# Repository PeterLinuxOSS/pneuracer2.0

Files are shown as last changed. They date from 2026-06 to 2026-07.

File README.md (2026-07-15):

# 🏎️ Pneuracer 2.0

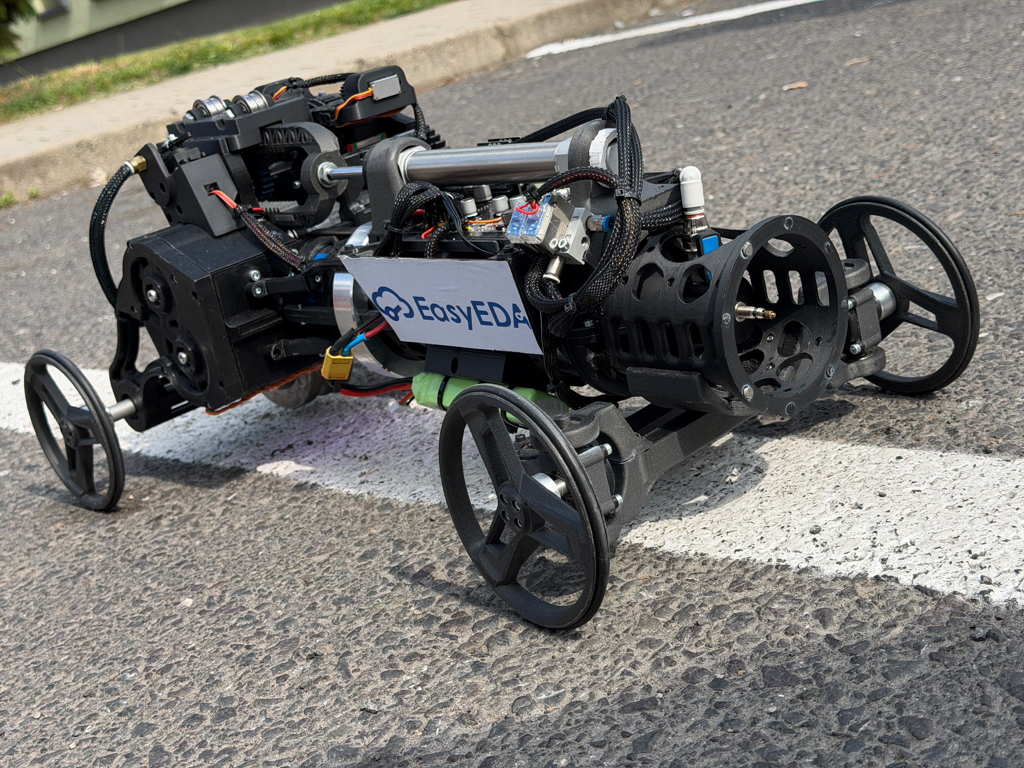
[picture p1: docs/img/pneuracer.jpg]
Pneuracer 2.0


> Control-system firmware for a **compressed-air powered** race car — no fuel, no electric motors.
> Student project by team **FLUJD** · SPŠ techniky a dizajnu, Poprad 🇸🇰

Two **ESP32-S3** chips (master + slave) talk over UART and together run the drivetrain, steering, tilt detection and diagnostics. Built with **PlatformIO** — one repository, two firmware images. Every part, circuit and line of code was designed and built by the team.

---

## 🏆 Highlights

- 🥇 **Regional winners** — ENERSOL SK (best project of the round)
- 🥈 **2nd place** — ENERSOL SK national → international final (Senica, V4 + Austria)
- 🥈 **2nd place** — Strojár Inovátor, TU Košice
- 4️⃣ **4th** — SOČ national
- 4️⃣ **4th / 40** — international Pneuracer, Brno *(+6 vs. last year)*

## 🚀 Quick start

```bash
git clone https://github.com/PeterLinuxOSS/pneuracer2.0.git
cd pneuracer2.0

pio run -e master_esp --target upload   # flash the master
pio run -e slave_esp  --target upload   # flash the slave
pio device monitor                      # 921600 baud
```

## 📚 Documentation

- 📖 **[Technical docs](docs/TECHNICAL.md)** — architecture, comms protocol, control modes, tuning, datasheets
- 📦 **[Bill of materials](docs/BOM.md)** — electronics + pneumatic kit
- 🔩 **[Hardware / PCB](docs/hardware/)** · 📐 **[Schematics](docs/schematics/)**
- 🗺️ **[Roadmap / TODO](TODO.md)** — planned improvements for the next PCB revision
- 📸 **[Gallery](docs/GALLERY.md)** — photos of the car and the team

## 🤝 Sponsors & partners

<p align="center">
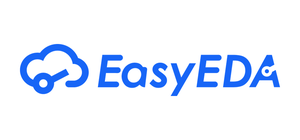
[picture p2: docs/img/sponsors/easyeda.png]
EasyEDA
  
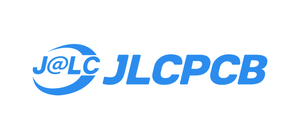
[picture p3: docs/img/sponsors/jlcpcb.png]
JLCPCB
  
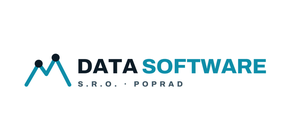
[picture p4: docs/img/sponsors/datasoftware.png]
DataSoftware s.r.o. Poprad
  
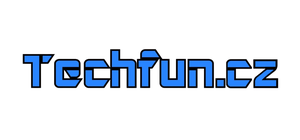
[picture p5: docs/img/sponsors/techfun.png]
Techfun.cz
  
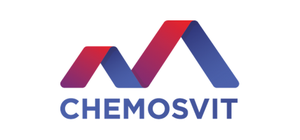
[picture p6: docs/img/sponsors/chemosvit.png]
Chemosvit
  
</p>

**[EasyEDA](https://easyeda.com)** & **[JLCPCB](https://jlcpcb.com)** — PCB design & manufacturing · **[DataSoftware](https://www.datasoftware.sk)** — electronic components · **[Techfun.cz](https://techfun.cz)** — electronics know-how & PCB review · **[Chemosvit](https://www.chemosvit.sk)** — travel & logistics. Huge thanks! 🙏

## 👤 Team

Team **FLUJD** — SPŠ techniky a dizajnu, Poprad 🇸🇰
**Peter Rigo** (lead — electronics, firmware) · Matej Mikita · Tomáš Frankovský · Tobias Cehula

📧 [rigopeter11@gmail.com](mailto:rigopeter11@gmail.com) · 📷 [@flujdsk](https://instagram.com/flujdsk)

## 📄 License

© 2026 Team FLUJD (Peter Rigo, Matej Mikita, Tomáš Frankovský, Tobias Cehula). Open source under copyleft:

- **Firmware & source code** — [GNU GPL v3.0](LICENSE). Derivatives must stay open-source under the same license.
- **Hardware, schematics, PCB files, CAD & documentation** — [CC BY-SA 4.0](LICENSE-HARDWARE.txt). Share alike, with attribution.

You are free to use, study, modify and share the project — just keep it open and credit **Team FLUJD**.

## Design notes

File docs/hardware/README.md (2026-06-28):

# 🔩 Hardware — PCB design files

EasyEDA Pro design files and manufacturing outputs for the Pneuracer 2.0 boards.

## Boards

| Folder | Board | Description |
|---|---|---|
| [`main-board/`](main-board/) | **Main board** (codename *Flujd*) | Carries the ESP32-S3 master/slave control electronics. |
| [`switching-regulator/`](switching-regulator/) | **Switching regulator** | Step-down power module — **2× placed on the main board**. |

## Files (per board)

| File | Description |
|---|---|
| `*.epro2` | EasyEDA Pro project (schematic + PCB) — open in [EasyEDA Pro](https://pro.easyeda.com) |
| `gerber.zip` | Gerber + drill files for manufacturing (e.g. JLCPCB) |
| `bom.xlsx` | Bill of materials for assembly |
| `pick-and-place.xlsx` | Component placement (CPL) for SMT assembly |
| `interactive-bom.html` | Interactive BOM — open in a browser for hand-assembly |

> System-level wiring schematics (draw.io) are in [`../schematics/`](../schematics/).
> Component-level BOM with order numbers is in [`../BOM.md`](../BOM.md).

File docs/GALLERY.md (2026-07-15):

# 📸 Gallery — Pneuracer 2.0

Photos of the car and the team from the 2025/2026 competition season.

<table>
  <tr>
    <td width="50%">Pneuracer 2.0<br><sub>The car — compressed-air powered, 3D-printed chassis</sub></td>
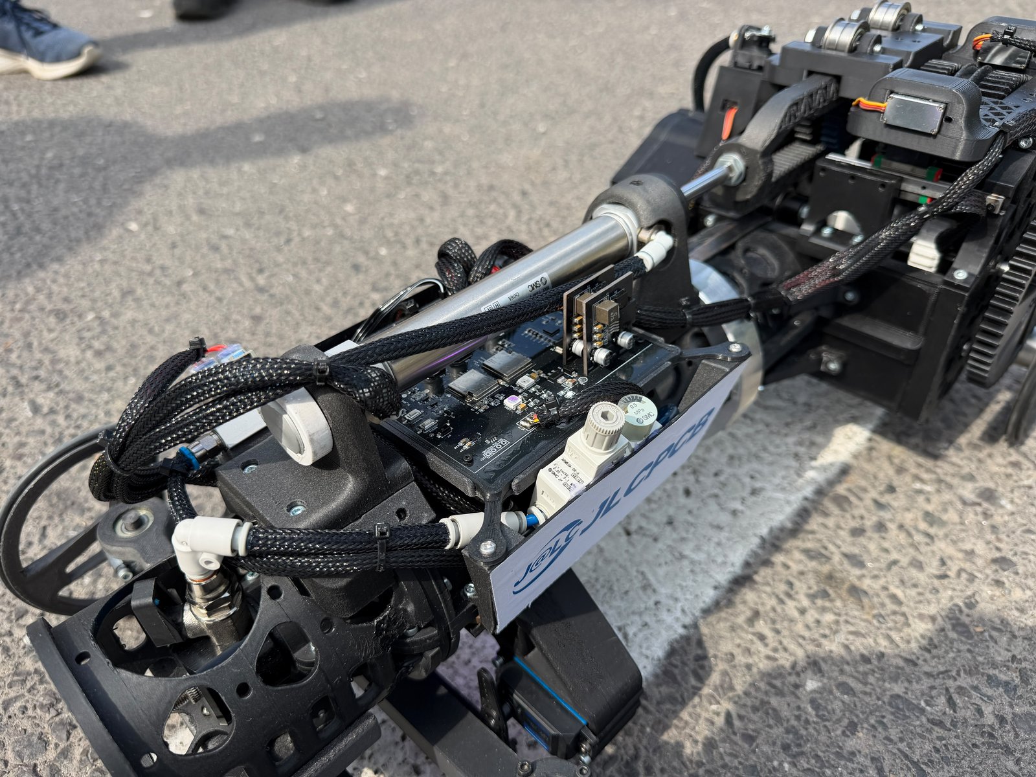
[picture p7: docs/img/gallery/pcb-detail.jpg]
Custom electronics
    <td width="50%"><br><sub>Custom ESP32-S3 control board & pneumatics on-board</sub></td>
  </tr>
  <tr>
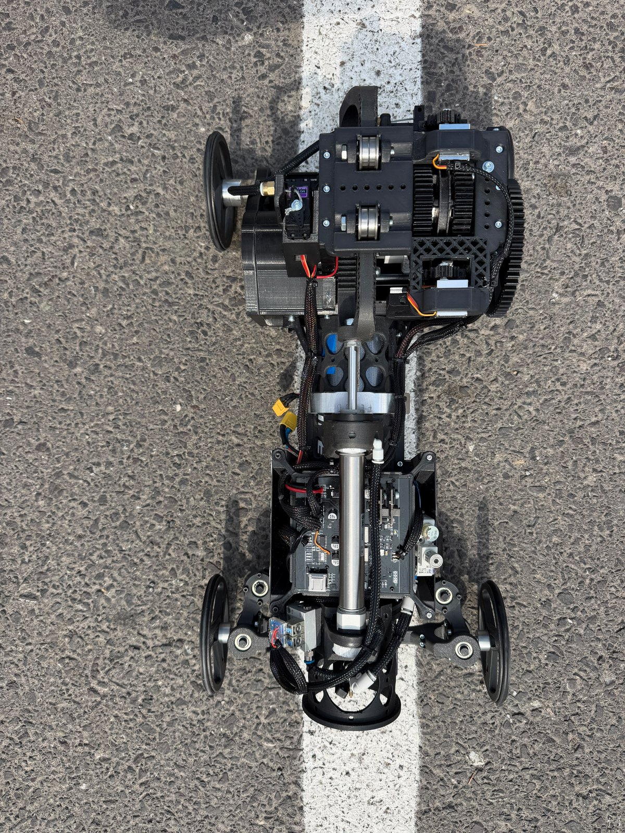
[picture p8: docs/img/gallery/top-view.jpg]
Top view
    <td width="50%"><br><sub>Top-down view — drivetrain & electronics layout</sub></td>
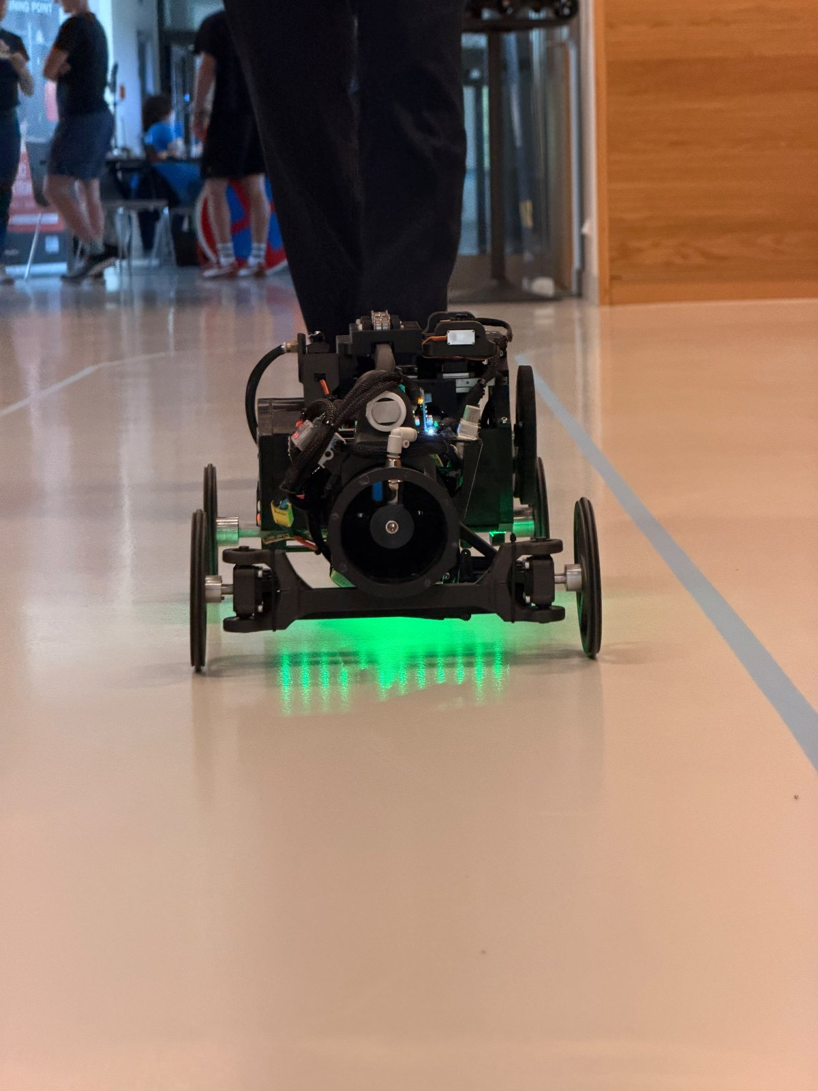
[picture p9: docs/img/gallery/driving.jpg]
Driving
    <td width="50%"><br><sub>Running at the international Pneuracer competition, Brno</sub></td>
  </tr>
  <tr>
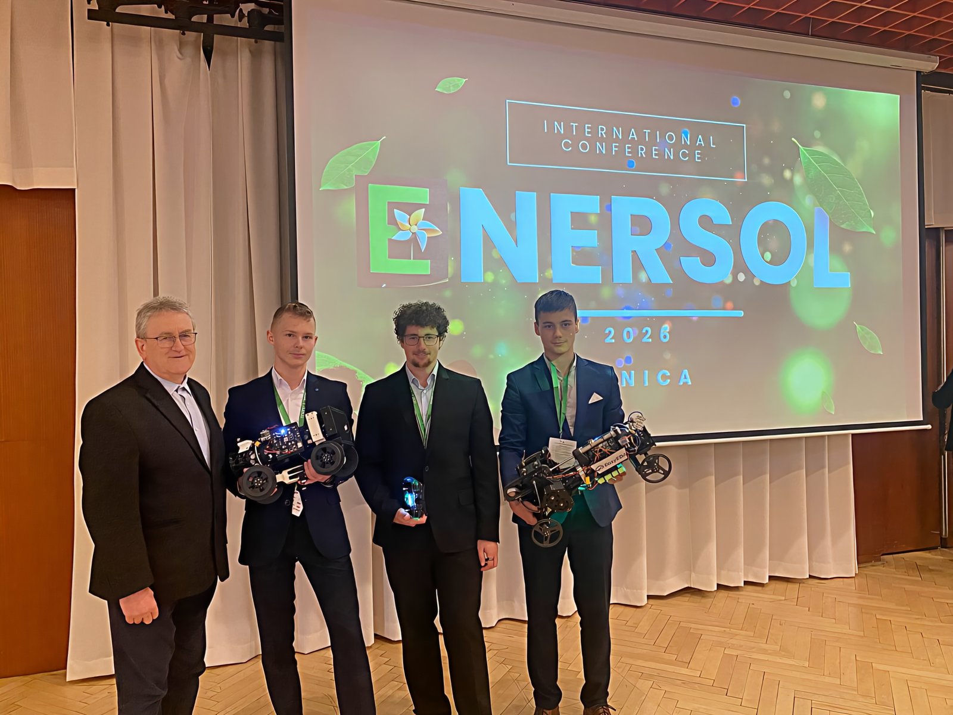
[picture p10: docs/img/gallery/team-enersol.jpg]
Team FLUJD at ENERSOL
    <td width="50%"><br><sub>Team FLUJD with the car at ENERSOL</sub></td>
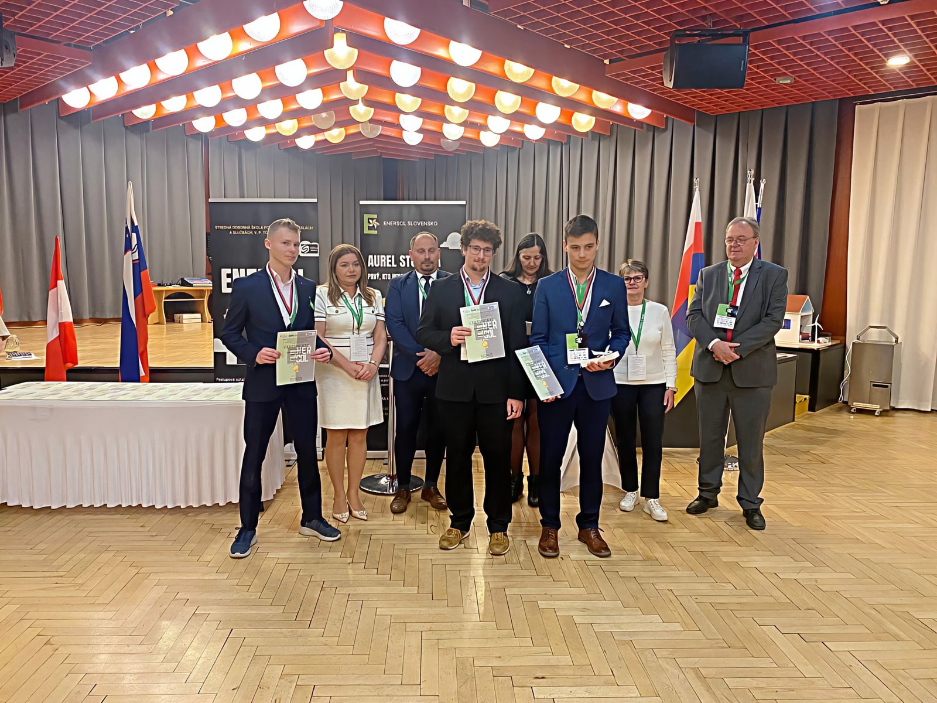
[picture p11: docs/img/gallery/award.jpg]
Award ceremony
    <td width="50%"><br><sub>Award ceremony — international ENERSOL final (V4 + Austria)</sub></td>
  </tr>
</table>

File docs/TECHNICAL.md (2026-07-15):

# 🔧 Pneuracer 2.0 — Technical documentation

Detailed technical reference for the Pneuracer 2.0 firmware. For a short overview see the [main README](../README.md).

---

## 🏗️ System architecture

Two ESP32-S3 chips communicate over UART; the shared `ControlPacket` structure ([`src/shared/SharedData.h`](../src/shared/SharedData.h)) defines the link.

```
[RC transmitter 2.4 GHz]
        │  ELRS/CRSF protocol
        ▼
┌──────────────────────────────┐              UART 921 600 baud               ┌─────────────────────────────────┐
│      ESP32-S3  MASTER        │ ◄───────────────────────────────────────────►│       ESP32-S3  SLAVE           │
│                              │          SharedData.h (ControlPacket)        │                                 │
│ • ELRS/CRSF receiver         │          header 0xBEEF + checksum            │ • Solenoid valves A/B           │
│ • IMU LSM6DS (tilt detect.)  │                                              │ • Pneumatic servo (gearbox)     │
│ • NeoPixel strip (29 LEDs)   │                                              │ • AS5600 magnetic encoder       │
│ • Servos: steering, brake    │                                              │ • Hall sensors (start/end)      │
│ • Buzzer                     │                                              │ • NeoPixel LED (1 pc)           │
│ • ADC: battery, current      │                                              │ • FreeRTOS TaskComms + Mutex    │
└──────────────────────────────┘                                              └─────────────────────────────────┘
```

---

## ⚙️ Hardware components

| Component | Side | Description |
|---|---|---|
| ESP32-S3 (×2) | Master + Slave | `esp32-s3-devkitc-1` |
| LSM6DS | Master | IMU — tilt detection |
| LSM6DSOX | Slave | IMU — supplementary measurement |
| AS5600 | Slave | Magnetic encoder (I²C) — angular speed °/s |
| Hall sensors | Slave | `HALL_START` pin 7, `HALL_END` pin 8, threshold 2000 |
| Solenoid valves | Slave | `VALVE_A` pin 6, `VALVE_B` pin 5 |
| Pneumatic servo | Slave | `SERVO_AIR_REG` pin 4 — gear shifting |
| ELRS receiver | Master | CRSF, Serial2: RX=4, TX=5 |
| NeoPixel strip | Master | 29 LEDs, pin 3 — Knight Rider boot animation |
| NeoPixel | Slave | 1 LED, pin 34 — status indication |
| Steering servo | Master | Pin 16 |
| Brake servo | Master | Pin 35 |
| Buzzer | Master | Pin 38, 1500 Hz |
| Battery ADC | Master | Pin 15, 3S LiPo (9–12.6 V) |
| Current ADC | Master | Pin 12 |

Full parts list (control electronics + SMC pneumatic kit): [`BOM.md`](BOM.md).

---

## 🔌 Master ↔ Slave communication protocol

The UART link runs at 921 600 baud. Every packet has a `0xBEEF` header and a checksum:

```cpp
// src/shared/SharedData.h
const uint16_t PACKET_HEADER = 0xBEEF;

struct __attribute__((packed)) ControlPacket {
    uint16_t header;         // 0xBEEF — packet identifier
    bool     motorEnable;    // motor enable
    int16_t  throttle;       // throttle from RC
    bool     elrsActive;     // ELRS link status
    int16_t  button;         // button state
    bool     haltIMU;        // pause IMU protection
    bool     brake;          // brake
    bool     Automatic;      // automatic mode
    int16_t  AutomaticSpeed; // controller setpoint (°/s)
    int16_t  Gear;           // requested gear
    uint8_t  checksum;       // checksum (summed XOR)
};
```

The slave processes packets in the FreeRTOS task `TaskComms` guarded by the `dataMutex` semaphore — the main loop never reads the data directly without locking.

---

## 🤖 Control modes (Slave)

**Manual mode** — the `throttle` value is mapped to the pause duration between valve switching. More throttle = shorter pause = higher output.

**Automatic mode — P controller** — the slave measures angular speed with the AS5600 encoder and compares it against the `AutomaticSpeed` setpoint, correcting the valve delay:

```cpp
float error      = automaticTargetSpeed - angular_speed;  // °/s
float adjustment = AUTO_KP * error;                       // KP = 0.04
currentDelayTarget -= (long)constrain(adjustment,
                                      -AUTO_MAX_ADJUSTMENT,
                                       AUTO_MAX_ADJUSTMENT);
```

**Automatic gear shifting:**

| Condition | Action | Servo (µs) |
|---|---|---|
| speed ≥ 1600 °/s | 3rd gear | 1200 |
| speed < 1400 °/s | 1st gear | 1800 |
| otherwise | Neutral | 1450 |

The hysteresis guard `GEAR_SHIFT_DELAY_MS = 250 ms` prevents rapid gear hunting.

---

## 🛠️ Building and flashing

**Requirements:** Visual Studio Code + PlatformIO extension, or the PlatformIO CLI (`pip install platformio`).

```bash
git clone https://github.com/PeterLinuxOSS/pneuracer2.0.git
cd pneuracer2.0

pio run -e master_esp --target upload   # flash the MASTER ESP32-S3
pio run -e slave_esp  --target upload   # flash the SLAVE ESP32-S3
pio device monitor                      # 921600 baud
```

> **Ports:** Master looks for `hwgrep://Standard COM Port`, Slave `hwgrep://Enhanced COM Port`.
> Change `upload_port` in `platformio.ini` to match your system if needed.

**Libraries** (PlatformIO downloads them automatically):

| Library | Version | Where |
|---|---|---|
| `Adafruit NeoPixel` | ^1.15.2 | Master + Slave |
| `CRSFforArduino` | ^2025.12.11 | Master |
| `Adafruit LSM6DS` | ^4.7.4 | Master + Slave |
| `ESP32Servo` | ^3.1.3 | Master + Slave |
| `AS5600` (robtillaart) | ^0.6.7 | Master + Slave |
| `Arduino_LSM6DSOX` | ^1.1.2 | Slave |

---

## 🎛️ Parameter tuning

All tunable values live in `config.h` — no "magic numbers" in the code.

`src/slave/config.h` — controller and valves:

```cpp
#define AUTO_KP               0.04f   // proportional gain
#define AUTO_MAX_ADJUSTMENT   15      // max delay change per cycle (ms)
#define AUTO_DEFAULT_SPEED    2000.0f // target speed when no setpoint arrives (°/s)
#define GEAR_UP_SPEED         1600.0f // shift up (°/s)
#define GEAR_DOWN_SPEED       1400.0f // shift down (°/s)
#define CONNECTION_TIMEOUT_MS 500     // failsafe on communication loss (ms)
```

`src/master/config.h` — battery and safety:

```cpp
#define TILT_WARNING_THRESHOLD   30.0f  // warning angle (°)
#define TILT_CRITICAL_THRESHOLD  45.0f  // critical angle (°)
#define BATTERY_VOLTAGE_MIN      9.0f   // min 3S LiPo voltage (V)
#define BATTERY_VOLTAGE_CRITICAL 9.0f   // triggers error state (V)
```

---

## 🧩 3D model (`Model/`)

The [`Model/`](../Model/) folder contains the 3D CAD model exported from **Onshape**:

- `Assembly 1.step` — full vehicle assembly in the neutral **STEP** format (ISO 10303); opens in any CAD package (Fusion 360, SolidWorks, FreeCAD, Onshape, …).
- Live Onshape document: <https://cad.onshape.com/documents/b738f9fed58a0fc4300e86a8/w/2e6fb48d5bbfbd61ad92da93/e/82aa846a4fa390a4291205c2>

---

## 🎮 Transmitter — EdgeTX SD card (`edgetx_sdcard/`)

Ready-to-use **EdgeTX** SD card content for the RadioMaster transmitter that controls the car over ELRS/CRSF.

- Firmware target: **`pocket`** · EdgeTX **v2.11.4**
- `MODELS/` — transmitter model configs (`model00.yml` … `model04.yml`), including the Pneuracer model
- `RADIO/` — global radio settings (`radio.yml`)
- `SCRIPTS/` — Lua scripts (functions, mixes, telemetry, tools, RGBLED, …)
- `SOUNDS/`, `SCREENSHOTS/`, `LOGS/`, `FIRMWARE/`, `BACKUP/` — standard EdgeTX directories

**Usage:** copy the contents of `edgetx_sdcard/` onto the transmitter's SD card (matching the firmware version above), then select the Pneuracer model on the radio.

---

## 📁 Repository structure

```
pneuracer2.0/
├── platformio.ini              # 2 build environments (master / slave)
├── src/
│   ├── shared/SharedData.h     # Shared ControlPacket structure
│   ├── master/                 # Master firmware (RC input, LEDs, servos, IMU)
│   │   ├── main.cpp  config.h  pins.h  globals.*  ELRS.h
│   │   ├── setups.*  tilt_detection.*  errors.*  functions.h  class.h
│   └── slave/                  # Slave firmware (valves, encoder, controller)
│       ├── main.cpp  config.h  pins.h
├── Model/                      # 3D CAD model (Onshape STEP export)
├── docs/
│   ├── TECHNICAL.md            # This file
│   ├── BOM.md                  # Bill of materials
│   ├── schematics/             # Electrical schematics (drawio + PNG + DXF/TIF)
│   └── hardware/               # EasyEDA Pro PCB projects + manufacturing files
│       ├── main-board/         # Main board "Flujd"
│       └── switching-regulator/ # Step-down regulator (2× on the main board)
├── edgetx_sdcard/              # EdgeTX SD card content (RadioMaster)
├── TODO.md                     # Roadmap / known issues for the next PCB revision
└── .pio/                       # PlatformIO build cache (not committed)
```

---

## 📚 References / Datasheets

- **ESP32-S3 / ESP32-WROOM-32** — <https://documentation.espressif.com/esp32-wroom-32_datasheet_en.pdf> · <https://www.espressif.com/en/products/socs/esp32-s3>
- **LDI1117 / LDL1117** LDO regulator — <https://www.tme.eu/Document/493515917c20095fb60cb61e6bcc216a/ldi1117u.pdf>
- **AL5809** LED driver (Diodes) — <https://www.diodes.com/assets/Datasheets/AL5809.pdf>
- **STEF12H60** eFuse (ST) — <https://www.st.com/resource/en/datasheet/stef12h60m.pdf>
- **IAUCN04S7N019D** N-MOSFET (Infineon) — <https://www.infineon.com/assets/row/public/documents/10/49/infineon-iaucn04s7n019d-datasheet-en.pdf>
- **LSM6DSO / LSM6DSOX** IMU (ST) — <https://www.st.com/resource/en/datasheet/lsm6dso.pdf>
- **AS5600** magnetic encoder — <https://techfun.sk/produkt/magneticky-rotacny-enkoder-as5600/>
- **WS2812B** addressable LED — <https://www.sdiplight.com/what-is-ws2812b-led-and-how-to-use-ws2812b-led/>
- **LiPo batteries** (RC Factory) — <https://www.rc-factory.eu/lipo-baterie>

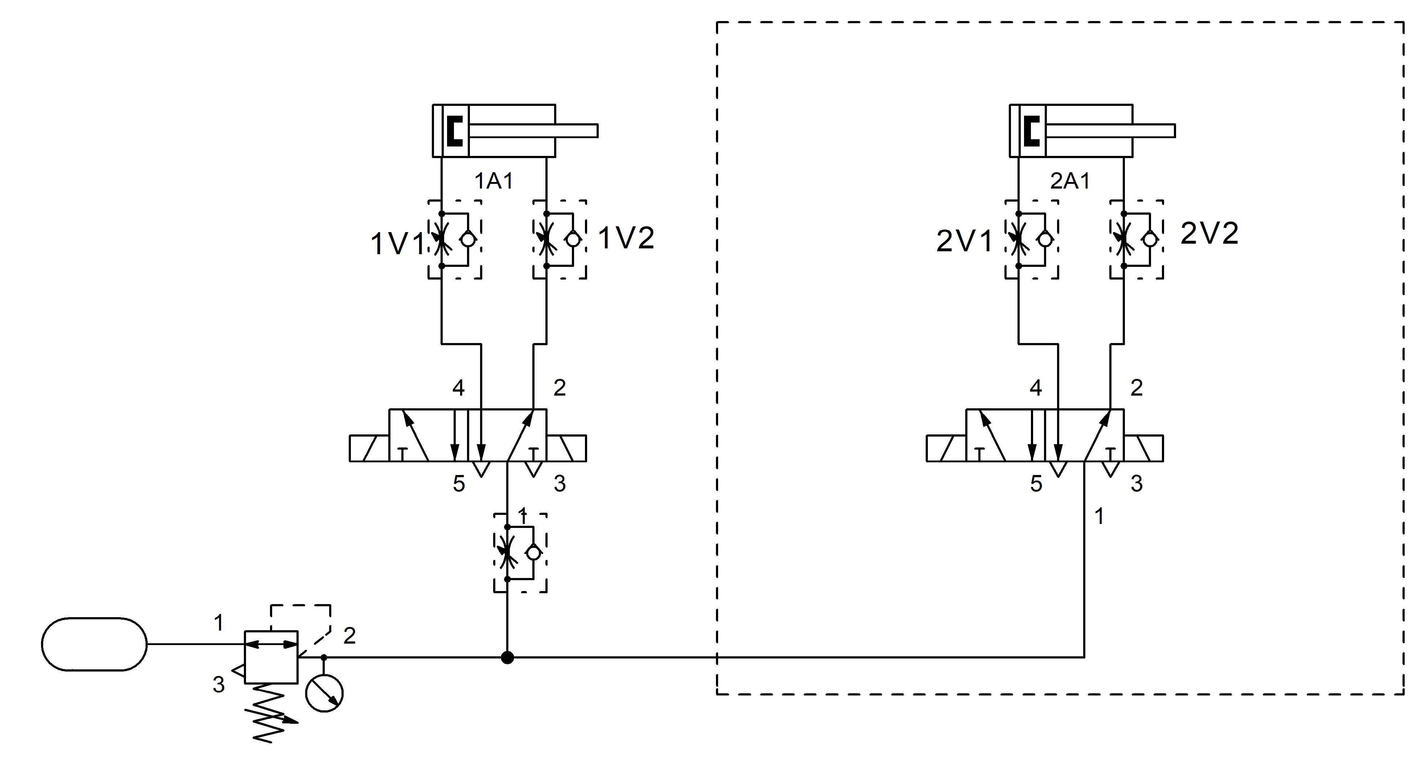
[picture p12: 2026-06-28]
docs/schematics/schema.tif

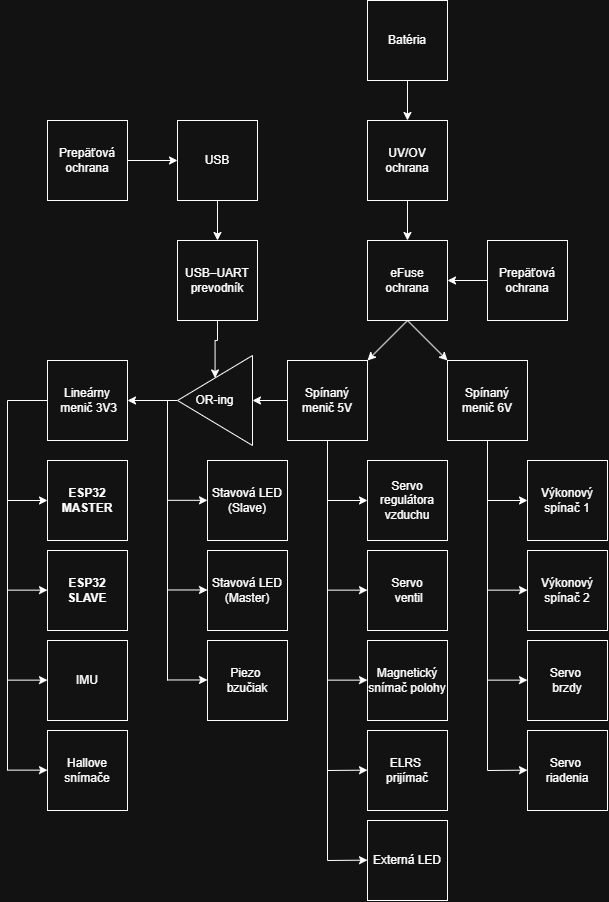
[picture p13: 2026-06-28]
docs/schematics/schema_power.drawio.png

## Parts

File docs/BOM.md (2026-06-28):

# 📦 Bill of Materials (BOM) — Pneuracer 2.0

Parts list for the Pneuracer 2.0 vehicle. The build splits into two groups:

1. **Control electronics** — the custom PCB / control system (chosen by the team).
2. **Pneumatic & mechanical kit** — the SOČ competition *Starter KIT* (SMC pneumatics) plus mechanical parts.

> Order numbers are kept as-is for traceability. SMC parts can be looked up by their order code on the manufacturer's site. Always verify availability before ordering.

---

## ⚡ Control electronics

| Part | Order no. / type | Qty | Note |
|---|---|-----|---|
| MCU | **ESP32-S3** (`esp32-s3-devkitc-1`) | 2 | Master + Slave |
| LDO regulator | **LDL1117S33R** / LDI1117 (3.3 V) | — | logic supply |
| eFuse | **STEF12H60** (ST) | — | protected power switch |
| LED driver | **AL5809** (Diodes) | — | constant-current |
| N-MOSFET | **IAUCN04S7N019D** (Infineon) | — | power switching |
| USB ESD protection | **USBLC6-2SC6** | — | USB data-line protection |
| Electrolytic cap | **Panasonic EEE-FT1E102UP** (1000 µF) | — | servo / eFuse decoupling |
| Connector / part | **C109102** | — | see project notes |
| IMU | **LSM6DSO / LSM6DSOX** | 1–2 | tilt detection (Master), aux (Slave) |
| Magnetic encoder | **AS5600** | 1 | I²C, angular speed (Slave) |
| Addressable LEDs | **WS2812B** (NeoPixel) | 30 | strip 29 (Master) + 1 (Slave) |
| Hall sensors | — | 2 | start / end of stroke (Slave) |
| Buzzer | — | 1 | 1500 Hz (Master) |

See [README → References / Datasheets](../README.md#-references--datasheets) for the datasheets of these parts.

---

## 🛠️ Pneumatic & mechanical kit (SOČ Starter KIT — SMC)

| Part | Order no. | Note |
|---|---|---|
| Air tank — Tire booster 1 L | — | max fill pressure 0.7 MPa, fillable with a regular bike pump |
| Regulator | **ARJ210-M5G** | M5 thread |
| Pneumatic cylinder | **CD85N20-100-B** (+ variants CD85N16/20/25, strokes 100/110/125) | max 2 cylinders per team total |
| Valve 3/2 | **V114-VGU** | incl. seal + screws |
| Manifold base — 1 valve | **V100-74-1** | |
| Manifold base — 2 valves | **VV100-S41-02-M5** | incl. "P" port plug + push-in fittings |
| In-line throttle valve Ø6 | **AS1001FG-06** | |
| Tubing Ø6 | **TU0604BU-100** | |
| Push-in fitting, straight | **KQ2H06-M5A** / **KQ2L06-M5A** | |
| T-fitting Ø6 | **KQ2T06-00A** | |
| Elbow fitting Ø6 | **KQ2L06-00A** | |
| U-fitting Ø6 | **KQ2U06-00A** | |
| Quick coupling | **VHK3A-06F-06F** | |
| Servo | **MG996R** 180° | |
| Linear rail + carriage | **MGN7**, length 250 mm | dratek.cz |
| Filament | **AURAPOL PLA HT110** 1.75 mm (black) | max 1 kg per team |

---

## 🛒 Allowed e-shops (SOČ rules)

- Filament: <https://www.aurapol.com/cz/>
- Electronics: <https://dratek.cz/>
- Transmitters / controllers: <https://www.bighobby.cz/>
- Models / wheels / mechanical parts: <https://www.promodels.cz/>
- Other: <https://www.briol.cz>, <https://e-shop.exvalos.cz>

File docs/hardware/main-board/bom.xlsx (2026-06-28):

No. | Quantity | Comment | Designator | Footprint | Value | Manufacturer Part | Manufacturer | Supplier Part | Supplier
1 | 2 | pad | +3V3,+5V | 2.2mm pad
2 | 1 | +5V Convertor | +5VCC | PAD-60-31-RECT
3 | 13 | Test-Point | +5VU,M34,M36,M37,S09,S10,S11,S12,SL_BOOT1,SL_RESET1,VBAT,VBATR,VCC | Test-Point-0.5mm
4 | 1 | +6V Convertor | +6VCC | PAD-60-31-RECT
5 | 4 | SERVO | Air_Reg_Servo,Brake_servo,Clutch_Servo,Steering_Servo | SERVO
6 | 1 | ARGB | aRGB | 3 PIN SMD CONNECTOR | Conn_01x03_Pin
7 | 1 | MASTER_BOOT | BOOT1 | SW-SMD_HX-3X6X2.5-X |  | MASTER_BOOT | hanxia(韩下) | C49234125 | LCSC
8 | 1 | Buzzer | BZ1 | Buzzer 5V
9 | 6 | 100nF | C7,C31,C36,C37,C47,C49 | C0805 | 100nF | FCC0805B104K500DT | FOJAN(富捷) | C5137467 | LCSC
10 | 3 | 10uF | C8,C24,C32 | C0805 | 10uF | FCC0805B104K500DT | FOJAN(富捷) |  | LCSC
11 | 11 | 100nF | C10,C27,C28,C29,C33,C44,C45,C50,C51,C52,C53 | C0805 | 100nF | FCC0805B104K500DT | FOJAN(富捷) |  | LCSC
12 | 2 | 100uF | C11,C35 | C0805 | 100uF | FCC0805B104K500DT | FOJAN(富捷) |  | LCSC
13 | 2 | 1uF | C12,C34 | C0805 | 1uF | FCC0805B104K500DT | FOJAN(富捷) |  | LCSC
14 | 1 | 10uF | C13 | C0805 | 10uF | C2012X6S1A156M125AC | TDK |  | LCSC
15 | 1 | 22uF | C14 | C0805 | 22uF | C2012X6S1A156M125AC | TDK |  | LCSC
16 | 4 | 100nF | C15,C16,C18,C20 | C0805 | 100nF | C2012X6S1A156M125AC | TDK |  | LCSC
17 | 1 | 2.2uF | C17 | C0805 | 2.2uF | C2012X6S1A156M125AC | TDK |  | LCSC
18 | 1 | 210uF | C19 | C0805 | 210uF | C2012X6S1A156M125AC | TDK |  | LCSC
19 | 1 | 3.3nF | C21 | C0805 | 3.3nF | C2012X6S1A156M125AC | TDK |  | LCSC
20 | 1 | 220nF | C22 | C0805 | 220nF | C2012X6S1A156M125AC | TDK |  | LCSC
21 | 3 | 0.1uF | C25,C26,C42 | C0805 | 0.1uF | FCC0805B104K500DT | FOJAN(富捷) |  | LCSC
22 | 1 | 4.7nF | C30 | C0805 | 4.7nF | C2012X6S1A156M125AC | TDK |  | LCSC
23 | 3 | 470uF | C38,C39,C40 | CAP-SMD_BD8.0-L8.3-W8.3-LS9.3-FD | 470uF | EMZS350ARA471MHA0G | NCC(日本贵弥功) | C2164331 | LCSC
24 | 1 | 1000uF | C41 | CAP-SMD_BD10.0-L10.3-W10.3-FD | 1000uF | EEEFT1E102UP | PANASONIC(松下) | C401766 | LCSC
25 | 2 | 4.7uF | C43,C46 | C0805 | 4.7uF | FCC0805B104K500DT | FOJAN(富捷) |  | LCSC
26 | 1 | XT30UPB-M | CN1 | CONN-TH_XT30UPB-M |  | XT30UPB-M | AMASS(艾迈斯) | C428721 | LCSC
27 | 1 | 2.54-2P WZDK-R Pitch Connector | CN2 | CONN-TH_2.54-2P-WZDK-R-PITCH-CONNECTOR |  | 2.54-2P WZDK-R Pitch Connector | SHOU HAN(首韩) | C49023803 | LCSC
28 | 3 | SMCJ15A | D3,D4,D9 | SMC_L6.9-W5.9-LS7.9-RD |  | SMCJ15A |  | C140796 | LCSC
29 | 2 | SS34 | D5,D6 | SMA-SMD_L4.4-W2.7-LS5.4-RD |  | SS34 | XUMAO(旭茂微) | C22448055 | LCSC
30 | 1 | SS14 | D7 | SMA_L4.3-W2.6-LS5.0-RD |  | SS14 | YONGYUTAI(永裕泰) | C47147601 | LCSC
31 | 4 | USBLC6-2SC6 | D8,D10,D13,D14 | SOT-23-6_L2.9-W1.6-P0.95-LS2.8-BL |  | USBLC6-2SC6 | GOODWORK(固得沃克) | C21713975 | LCSC
32 | 2 | SMF05CT1G | D11,D12 | SOT-363_L2.0-W1.3-P0.65-LS2.1-BR |  | SMF05CT1G | GOODWORK(固得沃克) | C28310462 | LCSC
33 | 1 | SMAJ6.5A | D15 | SMA_L4.3-W2.6-LS5.2-RD |  | SMAJ6.5A | FOSAN(富捷/富信) | C5353157 | LCSC
34 | 1 | SMAJ5.0A | D16 | SMA_L4.3-W2.6-LS5.1-RD |  | SMAJ5.0A | Brightking(君耀电子) | C20623816 | LCSC
35 | 1 | BZT52C3V6 | D17 | SOD-123_L2.7-W1.6-LS3.7-RD |  | BZT52C3V6 | R+O(宏嘉诚) | C19077397 | LCSC
36 | 1 | ELRS | ELRS | Radiomaster XR4
37 | 1 | ESP_POWER_LED | ESP_PWRL | LED0805-RD |  | ESP_POWER_LED | MEIHUA(美华) | C389523 | LCSC
38 | 2 | SS451A | HALL_END,HALL_START | TO-92S_3P-L4.1-W1.6-P1.27-L |  | SS451A | Honeywell(霍尼韦尔) | C396069 | LCSC
39 | 1 | I2C | I2C1 | I2C connector |  | I2C | XFCN(兴飞) | C2691448 | LCSC
40 | 1 | I2C2 | I2C2 | I2C connector |  | I2C2 | XFCN(兴飞) | C2691448 | LCSC
41 | 2 | Connector 3pin | J1,J2 | 3 PIN SMD CONNECTOR | Conn_01x03_Pin
42 | 2 | WS2812B-V5 | LED4,LED8 | LED-SMD_4P-L5.0-W5.0-LS5.4-TL-1 |  | WS2812B-V5 | worldsemi | C2846931 | LCSC
43 | 1 | MNG-Fault | LED8-RED1 | LED0805-RD |  | MNG-Fault | MEIHUA(美华) | C389523 | LCSC
44 | 15 | 10k | MG-R4,R13,R21,R24,R25,R33,R37,R38,R46,R47,R48,R52,R53,R54,R55 | R0805 | 10k | FRC0805F1602TS | FOJAN(富捷) |  | LCSC
45 | 4 | AO3401 | Q1,Q8,Q16,Q18 | SOT-23-3_L2.9-W1.3-P1.90-LS2.4-BR |  | AO3401 | MOT(仁懋) | C39847031 | LCSC
46 | 5 | 2N7002 | Q2,Q6,Q7,Q15,Q17 | SOT-23-3_L2.9-W1.3-P1.90-LS2.4-BR |  | 2N7002 | YFW(佑风微) | C42395051 | LCSC
47 | 1 | IAUCN04S7L053DATMA1 | Q3 | DFN-8_L5.5-W5.2-P1.27-LS6.0-BL-EP2 |  | IAUCN04S7L053DATMA1 | Infineon(英飞凌) | C32162449 | LCSC
48 | 4 | BC847 | Q11,Q12,Q13,Q14 | SOT-23-3_L2.9-W1.3-P1.90-LS2.4-BR |  | BC847 | SHIKUES(时科) | C475630 | LCSC
49 | 4 | 12kΩ | R1,R12,R34,R35 | R0805 | 12kΩ | FRC0805F1602TS | FOJAN(富捷) |  | LCSC
50 | 2 | 150R | R11,R41 | R0805 | 150R | FRC0805F1602TS | FOJAN(富捷) |  | LCSC
51 | 2 | 4.7kΩ | R14,R15 | R0805 | 4.7kΩ | FRC0805J103TS | FOJAN(富捷) |  | LCSC
52 | 1 | 47R | R16 | R0805 | 47R | FRC0805F1602TS | FOJAN(富捷) |  | LCSC
53 | 1 | 4K | R17 | R0805 | 4K | FRC0805F1602TS | FOJAN(富捷) |  | LCSC
54 | 1 | 28k | R18 | R0805 | 28k | FRC0805F1602TS | FOJAN(富捷) |  | LCSC
55 | 1 | 6k2 | R19 | R0805 | 6k2 | FRC0805F1602TS | FOJAN(富捷) |  | LCSC
56 | 1 | 22k | R20 | R0805 | 22k | FRC0805F1602TS | FOJAN(富捷) |  | LCSC
57 | 2 | 100R | R23,R32 | R0805 | 100R | FRC0805F1602TS | FOJAN(富捷) |  | LCSC
58 | 5 | 100K | R28,R60,R61,R62,R63 | R0805 | 100K | FRC0805F1602TS | FOJAN(富捷) |  | LCSC
59 | 1 | 18K | R29 | R0805 | 18K | FRC0805F1602TS | FOJAN(富捷) |  | LCSC
60 | 4 | 2k2 | R39,R40,R56,R57 | R0805 | 2k2 | FRC0805F1602TS | FOJAN(富捷) |  | LCSC
61 | 4 | 1K | R42,R43,R44,R45 | R0805 | 1K | FRC0805F1602TS | FOJAN(富捷) |  | LCSC
62 | 1 | 4k7 | R49 | R0805 | 4k7 | FRC0805F1602TS | FOJAN(富捷) |  | LCSC
63 | 2 | 22R | R50,R51 | R0805 | 22R | FRC0805F1602TS | FOJAN(富捷) |  | LCSC
64 | 2 | 10K | R58,R59 | R0805 | 10K | FRC0805F1602TS | FOJAN(富捷) |  | LCSC
65 | 1 | MASTER_RESET | RESET1 | SW-SMD_HX-3X6X2.5-X |  | MASTER_RESET | hanxia(韩下) | C49234125 | LCSC
66 | 1 | 6k8 | R_OV_Bot | R0805 | 6k8 | FRC0805F1602TS | FOJAN(富捷) |  | LCSC
67 | 1 | 200k | R_OV_Top | R0805 | 200k | FRC0805F1602TS | FOJAN(富捷) |  | LCSC
68 | 1 | 27k | R_UV_Bot | R0805 | 27k | FRC0805F1602TS | FOJAN(富捷) |  | LCSC
69 | 1 | 180k | R_UV_Top | R0805 | 180k | FRC0805F1602TS | FOJAN(富捷) |  | LCSC
70 | 1 | LDL1117S33R | U4 | SOT-223-3_L6.5-W3.4-P2.30-LS7.0-BR |  | LDL1117S33R | ST(意法半导体) | C970558 | LCSC
71 | 2 | BTS5030-2EKA | U8,U15 | PG-DSO-14_L8.7-W3.9-P1.27-LS6.0-BL-EP |  | BTS5030-2EKA | Infineon(英飞凌) | C534808 | LCSC
72 | 1 | STEF12H60MAPUR | U9 | QFN-32_L5.0-W5.0-P0.50-TL-EP3.5 |  | STEF12H60MAPUR | ST(意法半导体) | C5267846 | LCSC
73 | 2 | AL5809-20 | U11,U13 | POWERDI123_L2.8-W1.8-LS3.7-FD |  | AL5809-20 | DIODES(美台) | C2653361 | LCSC
74 | 1 | LTC4368CMS-1#PBF | U12 | MSOP-10_L3.0-W3.0-P0.50-LS5.0-BL |  | LTC4368CMS-1#PBF | ADI(亚德诺) | C688384 | LCSC
75 | 2 | RF_Module_ESP32-S3-MINI-1U | U17,U23 | BULETM-SMD_ESPRESSIF_ESP32-S3-MINI-1U-N8 | ESP32-S3-MINI-1U-N8
76 | 1 | LSM6DSOTR | U21 | LGA-14_L3.0-W2.5-P0.50-TL |  | LSM6DSOTR | ST(意法半导体) | C2655100 | LCSC
77 | 1 | CP2105-F01-GMR | U22 | QFN-24_L4.0-W4.0-P0.50-BL-EP2.6 |  | CP2105-F01-GMR | SKYWORKS/SILICON LABS(芯科) | C109102 | LCSC
78 | 1 | SN74HC125DR | U24 | SOIC-14_L8.7-W3.9-P1.27-LS6.0-BL |  | SN74HC125DR | TI(德州仪器) | C42322 | LCSC
79 | 2 | 74LVC1G125GW | U25,U26 | SOT-353-5_L2.0-W1.6-P0.65-LS2.1-BL |  | 74LVC1G125GW | MDD(辰达半导体) | C52140430 | LCSC
80 | 1 | PESD3V3L1BA | U27 | SOD-323_L1.8-W1.3-LS2.5-BI |  | PESD3V3L1BA | Leiditech(雷卯电子) | C5210989 | LCSC
81 | 1 | 292303-1 | USB1 | USB-A-TH_USB-302-T |  | 292303-1 | TE Connectivity(泰科电子) | C86461 | LCSC
82 | 4 | Y_LED | V1-OA1,V1-OB1,V2-OA1,V2-OB1 | LED0603-FD |  | Y_LED | YONGYUTAI(永裕泰) | C19273153 | LCSC
83 | 1 | V_GOK | V_GOK | LED0805-RD |  | V_GOK | MEIHUA(美华) | C389523 | LCSC

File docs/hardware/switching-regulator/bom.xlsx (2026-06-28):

No. | Quantity | Comment | Designator | Footprint | Value | Manufacturer Part | Manufacturer | Supplier Part | Supplier
1 | 2 | 1uF | Cbst,CinX | C0805 | 1uF | CC0805KKX7R9BB105 | YAGEO(国巨) | C91185 | LCSC
2 | 2 | 10uF | Cin1,Cin2 | C0805 | 10uF | CC0805KKX7R9BB105 | YAGEO(国巨) |  | LCSC
3 | 2 | 100uF | Cin4,Cout4 | CAP-SMD_BD5.0-L5.3-W5.3_RVE1H100M0505 | 100uF | RVE1H100M0505 | RS(容硕) |  | LCSC
4 | 3 | 47uF | Cout1,Cout2,Cout3 | C1206 | 47uF | CL31A476MPHNNNE | SAMSUNG(三星) | C96123 | LCSC
5 | 3 | pad | GND,GND1,VOUT | PAD V2.1
6 | 1 | XAL6060-472MEB | L1 | IND-SMD_L8.9-W8.5 | 4.7uH
7 | 1 | PW_OK | LED1 | LED0805-RD |  | PW_OK | MEIHUA(美华) | C389523 | LCSC
8 | 1 | 1kΩ | Rfbb | R0805 | 1kΩ | FRC0805J103TS | FOJAN(富捷) |  | LCSC
9 | 1 | 3kΩ | Rfbt | R0805 | 3kΩ | FRC0805J472 TS | FOJAN(富捷) |  | LCSC
10 | 1 | LM22679TJ-ADJ/NOPB | U1 | TO-263-7_L10.2-W9.9-P1.27-LS14.0-BL |  | LM22679TJ-ADJ/NOPB | TI(德州仪器) | C110378 | LCSC
11 | 1 | SS54LC | U2 | DO-214AB_L6.9-W5.9-LS7.9-RD |  | SS54LC |  | C9900094654 | LCSC
12 | 1 | AL5809-10 | U10 | POWERDI123_L2.8-W1.8-LS3.7-FD |  | AL5809-10 | DIODES(美台) | C2653361 | LCSC
13 | 1 | VBAT | Z1 | PAD V2.1

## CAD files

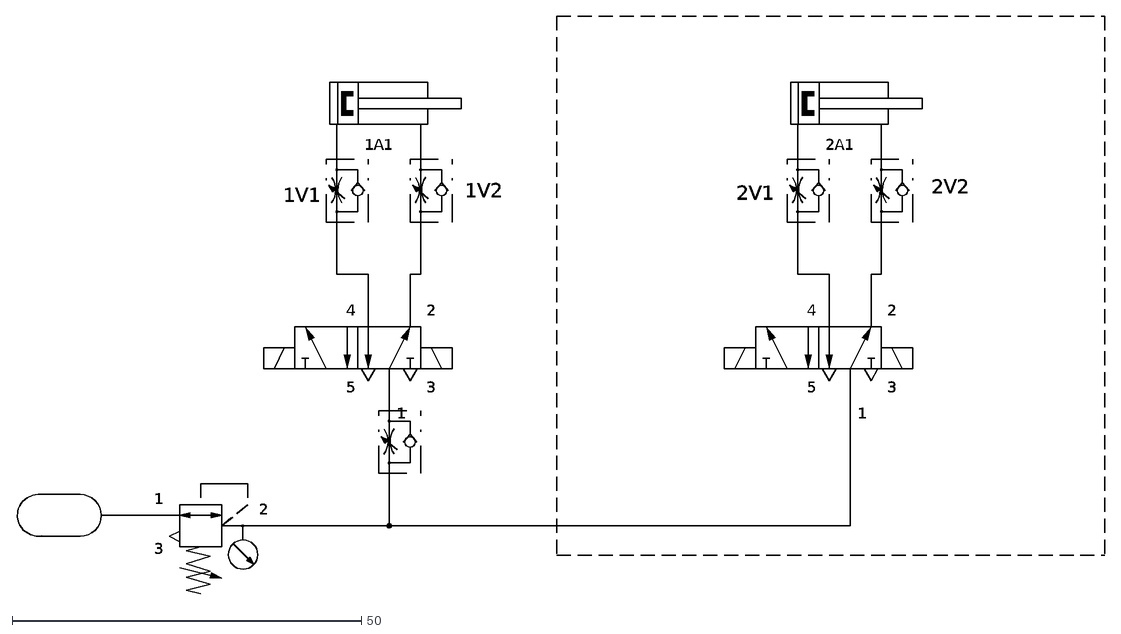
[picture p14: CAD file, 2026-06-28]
docs/schematics/schema.dxf
1A1
4
2
5
1
3
2A1
1V1
1V2
2V2
2V1

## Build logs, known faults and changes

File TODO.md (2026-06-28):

# 📝 TODO / Roadmap — Pneuracer 2.0

Improvements and known issues collected during development, intended for the **next PCB revision** and firmware iterations.

## 🔌 Hardware / PCB (next revision)

- [ ] Add the missing **electrolytic capacitors** for the servos — and review the eFuse that was damaged because they were missing.
- [ ] Hall sensor **decoupling capacitor**.
- [ ] **Transistor gain** stage for the solenoid drivers.
- [ ] **RC snubber** across the solenoids (flyback / spike suppression).
- [ ] Coil **pin 1** → route as input to the converter.
- [ ] Add **74HC125 buffer** for the servo signals.
- [ ] Let the ESP32 **detect whether it is powered from USB or battery**.
- [ ] Add **spare GPIO pins** broken out for future use.
- [ ] Add dedicated **debug pins**.

## 🧰 PCB layout guidelines (apply next time)

- Saturation **vias don't need to connect to the GND power plane** (currently a saturation via is tied to the supply/GND plane — fix).
- **Layer stack-up:** keep the signal layer as close to the GND plane as possible; mind dielectric thickness.
- **Vias:** don't place vias directly under a pad — offset them to the side where possible (the via sits slightly lower than the pad).
- **Crosstalk:** keep signal traces — especially analog — far apart, at least 3× the trace width.

## 🐞 Known issues

- Missing electrolytic capacitors for servos caused the **eFuse to fail**.
- Saturation vias are incorrectly connected to the GND power plane.

---

*Source: development notes (SOČ project, team FLUJD).*

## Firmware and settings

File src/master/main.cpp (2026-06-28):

#include <Arduino.h>
#include <Adafruit_NeoPixel.h>
#include "pins.h"
#include "ELRS.h" // ELRS Manager
#include <CRSFforArduino.hpp>
#include <ESP32Servo.h>
#include <ESP32PWM.h>
#include <Adafruit_LSM6DS.h> // 6-axis IMU (accel + gyro)
#include "shared/SharedData.h"
#include "globals.h"
#include "functions.h"
#include "setups.h"
#include "errors.h"
#include "tilt_detection.h"

// --- KNIGHT RIDER (KITT) SCANNER ANIMATION ---
// Physical LEDs 0-16: individual. LEDs 17-28 (12 pcs): grouped as one virtual LED.
// Positions and timing are configured in config.h.
static int8_t        krPos = 0;
static int8_t        krDir = 1;
static unsigned long krLast = 0;
static uint8_t       krR = 255, krG = 0, krB = 0; // current color — change via setKnightRiderColor()

void setKnightRiderColor(uint8_t r, uint8_t g, uint8_t b) {
    krR = r; krG = g; krB = b;
}

static void krSetVirt(int virt, uint8_t r, uint8_t g, uint8_t b) {
    if (virt < KR_GROUP_START) {
        pixels.setPixelColor(virt, pixels.Color(r, g, b));
    } else {
        for (int p = KR_GROUP_START; p < NEOPIXEL_COUNT; p++)
            pixels.setPixelColor(p, pixels.Color(r, g, b));
    }
}

bool knightRiderStep() {
    unsigned long now = millis();
    if (now - krLast < KR_STEP_MS) return false;
    krLast = now;

    pixels.clear();

    // Fading tail — scales all color channels
    for (uint8_t t = 1; t <= KR_TAIL; t++) {
        int tidx = krPos - krDir * (int)t;
        if (tidx >= 0 && tidx < KR_VIRT_COUNT) {
            uint8_t scale = 255 - (255 / (KR_TAIL + 1)) * t;
            krSetVirt(tidx,
                      (uint8_t)((krR * scale) >> 8),
                      (uint8_t)((krG * scale) >> 8),
                      (uint8_t)((krB * scale) >> 8));
        }
    }
    // Full-bright head
    krSetVirt(krPos, krR, krG, krB);

    krPos += krDir;
    if (krPos >= KR_VIRT_COUNT) { krPos = KR_VIRT_COUNT - 2; krDir = -1; }
    if (krPos < 0)              { krPos = 1;                  krDir =  1; }

    return true;
}

void bootKnightRider(unsigned long durationMs, uint8_t r, uint8_t g, uint8_t b) {
    setKnightRiderColor(r, g, b); 
    krPos = 0; krDir = 1; krLast = 0; // reset animation state
    unsigned long start = millis();
    while (millis() - start < durationMs) {
        if (knightRiderStep()) pixels.show();
        delay(1);
    }
    pixels.clear();
    pixels.show();
    setKnightRiderColor(255,0,255); // purple
}

// --- FUNCTION IMPLEMENTATIONS IN MAIN.CPP ---

void beep(int duration_ms, int frequency)
{
    ledcSetup(0, frequency, 8);
    ledcWrite(0, 180);
    delay(duration_ms);
    ledcWrite(0, 0);
};

void requestBeepPattern(uint8_t type, uint8_t count, uint16_t frequency, uint16_t duration_ms, uint16_t gap_ms)
{
    portENTER_CRITICAL(&sharedMux);
    if (beepRequestPending && beepRequestType == BEEP_ERROR) {
        portEXIT_CRITICAL(&sharedMux);
        return;
    }
    beepRequestType = (BeepPatternType)type;
    beepRequestCount = count;
    beepRequestFrequency = frequency;
    beepRequestDuration = duration_ms;
    beepRequestGap = gap_ms;
    beepRequestPending = true;
    portEXIT_CRITICAL(&sharedMux);
}

void calibrate_imu()
{
    int numSamples = 500;
    sensors_event_t accel, gyro, temp;

    for (int i = 0; i < numSamples; i++)
    {
        // Use a non-blocking loop structure for sampling
        lsm6ds.getEvent(&accel, &gyro, &temp);

        gyroXoffset += gyro.gyro.x;
        gyroYoffset += gyro.gyro.y;
        gyroZoffset += gyro.gyro.z;

        // For Accel: We assume Z is pointing up (1G), so we calibrate X and Y to 0
        accelXoffset += accel.acceleration.x;
        accelYoffset += accel.acceleration.y;
        accelZoffset += (accel.acceleration.z - 9.806); // Subtract Earth's gravity

        delay(10); // Match your data rate (10ms = 100Hz)
    }

    gyroXoffset /= numSamples;
    gyroYoffset /= numSamples;
    gyroZoffset /= numSamples;

    accelXoffset /= numSamples;
    accelYoffset /= numSamples;
    accelZoffset /= numSamples;

    lsm6ds.getEvent(&accel, &gyro, &temp);
    Serial.println("Calibration Complete!");
    Serial.printf("Gyro Offsets: X=%.2f Y=%.2f Z=%.2f\n", gyroXoffset, gyroYoffset, gyroZoffset);
    Serial.printf("Temp: %.2f C\n", temp.temperature);
    beep(150, 2000);
    delay(100);
    beep(150, 2500);
    delay(100);
    beep(200, 3000);
}

void setup()
{
    ESP32PWM::allocateTimer(1);
    ESP32PWM::allocateTimer(2);
    ESP32PWM::allocateTimer(3);
    analogReadResolution(12);

    setup_NeoPixel();
    bootKnightRider(BOOT_ANIM_DURATION_MS, 255, 255, 255);

    slavePower.init();

    Serial.begin(921600); // USB Debug
    Serial1.begin(921600, SERIAL_8N1, INTER_TX_S, INTER_RX_S);
    Serial.println("Starting MASTER setup...");

    setup_valves();
    setup_buzzer();
    beep(200, 1500);
    setup_battery();
    setup_imon();
    setup_button();
    setup_imu();
    delay(300);

    Serial.println("IMU initialized, calibrating...");
    beep(200, 3000);

    calibrate_imu();
    Serial.println("IMU calibration complete!");
    setup_CRSF();
    Serial.println("CRSF setup complete!");
    setup_ServoPWM();

    xTaskCreatePinnedToCore(
        TaskSlaveComms,
        "SlaveComms",
        4096,
        NULL,
        1,
        NULL,
        0);
    slavePower.enablePower();

    // ✓ Setup OK - Signal success
    signalSuccess();
    Serial.println("MASTER Setup Complete. Running Multithreaded.");
}

// --- IMU SENSOR READING ---
void read_and_display_imu()
{

    sensors_event_t accel, gyro, temp;
    lsm6ds.getEvent(&accel, &gyro, &temp);

    // Subtract the offsets
    float corrected_gx = gyro.gyro.x - gyroXoffset;
    float corrected_gy = gyro.gyro.y - gyroYoffset;
    float corrected_gz = gyro.gyro.z - gyroZoffset;

    float corrected_ax = accel.acceleration.x - accelXoffset;
    float corrected_ay = accel.acceleration.y - accelYoffset;
    float corrected_az = accel.acceleration.z - accelZoffset;

    unsigned long imuNow = millis();

    // --- DEBUG: Show raw values ---
    static unsigned long lastDebugTime = 0;
    if (imuNow - lastDebugTime > 500) {
        Serial.printf("[DEBUG] Gyro: X=%.2f Y=%.2f Z=%.2f | Accel: X=%.2f Y=%.2f Z=%.2f\n",
                      corrected_gx, corrected_gy, corrected_gz,
                      corrected_ax, corrected_ay, corrected_az);
        lastDebugTime = imuNow;
    }

    // --- DETECT ABNORMAL TILT (COMPLEMENTARY FILTER: GYRO + ACCEL) ---
    TiltData tilt = detect_abnormal_tilt(corrected_ax, corrected_ay, corrected_az,
                                         corrected_gx, corrected_gy, corrected_gz);

    // --- DEBUG: Always show tilt angles ---
    static unsigned long lastTiltTime = 0;
    if (imuNow - lastTiltTime > 500) {
        Serial.printf("[TILT] Roll: %.1f° | Pitch: %.1f° | Threshold: %.1f°\n",
                      tilt.roll, tilt.pitch, TILT_WARNING_THRESHOLD);
        lastTiltTime = imuNow;
    }

    static unsigned long haltClearStart = 0;
    float maxTilt = max(abs(tilt.roll), abs(tilt.pitch));
    const float TILT_RECOVERY_THRESHOLD = TILT_WARNING_THRESHOLD - 5.0f;

    if (tilt.isAbnormal)
    {
        haltIMU = true; // Set flag - TaskSlaveComms will handle beeping
        haltClearStart = 0;
        Serial.printf("  🚨 Roll: %.1f° | Pitch: %.1f° %s\n",
                      tilt.roll, tilt.pitch, tilt.isCritical ? "[CRITICAL]" : "[WARNING]");
    }
    else if (haltIMU)
    {
        if (maxTilt < TILT_RECOVERY_THRESHOLD)
        {
            if (haltClearStart == 0)
            {
                haltClearStart = millis();
            }
            else if (millis() - haltClearStart >= 2000)
            {
                haltIMU = false;
                haltClearStart = 0;
                Serial.println("  ✅ Tilt returned to normal, clearing haltIMU");
            }
        }
        else
        {
            haltClearStart = 0;
        }
    }
}


static uint8_t batteryVoltageToPercent(float v) {
    // 3S LiPo discharge curve (non-linear approximation)
    static const float voltages[] = {9.0f, 9.6f, 10.2f, 10.8f, 11.1f, 11.4f, 11.7f, 12.0f, 12.3f, 12.6f};
    static const uint8_t percents[] = {0, 5, 15, 30, 50, 65, 78, 88, 95, 100};
    const int n = sizeof(voltages) / sizeof(voltages[0]);
    if (v <= voltages[0]) return 0;
    if (v >= voltages[n - 1]) return 100;
    for (int i = 1; i < n; i++) {
        if (v <= voltages[i]) {
            float t = (v - voltages[i - 1]) / (voltages[i] - voltages[i - 1]);
            return (uint8_t)(percents[i - 1] + t * (percents[i] - percents[i - 1]));
        }
    }
    return 100;
}

void check_battery()
{
    unsigned long now = millis();

    int rawADC = analogRead(VBAT_REF);
    int rawImon = analogRead(IMON_CURRENT);

    float voltageImon = (rawImon * ADC_REF_VOLTAGE) / ADC_RESOLUTION;
    imonCurrent = voltageImon / IMON_CONVERSION_FACTOR;

    batteryVoltage = (rawADC / (float)ADC_RESOLUTION) * ADC_REF_VOLTAGE * VBAT_DIVIDER_RATIO;
    bool currentlyConnected = batteryVoltage >= BATTERY_DISCONNECTED_THRESHOLD;

    // Check for rapid voltage drop (indicates battery disconnection)
    float voltageDrop = previousBatteryVoltage - batteryVoltage;
    bool rapidDrop = (previousBatteryVoltage > 0) && (voltageDrop > BATTERY_DROP_THRESHOLD);
    if (rapidDrop)
    {
        ignoreLowBatteryUntil = millis() + BATTERY_LOW_IGNORE_MS;
        Serial.println("RAPID VOLTAGE DROP DETECTED - ignoring low battery for 5s");
    }
    previousBatteryVoltage = batteryVoltage;

    if (!currentlyConnected)
    {
        if (batteryConnected)
        {
            Serial.println("BATTERY DISCONNECTED - switching to USB power");
            requestBeepPattern(BEEP_BATTERY_DISCONNECT, 2, 1200, 120, 80);
        }
        batteryConnected = false;
        usbPower = true;
        batteryPercent = 100;

        if (activeErrorCode == ERR_BATTERY_LOW)
        {
            errorActive = false;
            activeErrorCode = ERR_NONE;
            errorCritical = false;
            haltIMU = false;
        }

        if (crsf)
        {
            crsf->telemetryWriteBattery(BATTERY_VOLTAGE_MAX, 0, (uint32_t)(AutomaticSpeed / 100), batteryPercent);
        }
        return;
    }

    if (!batteryConnected)
    {
        Serial.printf("BATTERY CONNECTED: %.2fV - switching to battery power\n", batteryVoltage);
        requestBeepPattern(BEEP_BATTERY_CONNECT, 3, 2000, 100, 80);
        batteryConnected = true;
        usbPower = false;
    }

    batteryPercent = batteryVoltageToPercent(batteryVoltage);

    if (crsf)
    {
        crsf->telemetryWriteBattery(batteryVoltage, 0, (uint32_t)(AutomaticSpeed / 100), batteryPercent);
    }

    if (batteryVoltage < BATTERY_VOLTAGE_CRITICAL && currentlyConnected && !rapidDrop && millis() > ignoreLowBatteryUntil)
    {
        lowBatteryCounter++;
        if (lowBatteryCounter >= BATTERY_LOW_CONFIRM_COUNT)
        {
            Serial.printf("CRITICAL BATTERY: %.2fV < %.2fV\n", batteryVoltage, BATTERY_VOLTAGE_CRITICAL);
            signalError(ERR_BATTERY_LOW, true);
            lowBatteryCounter = 0; // Reset counter after triggering error
        }
    }
    else
    {
        lowBatteryCounter = 0; // Reset counter if voltage recovers or rapid drop
        if (activeErrorCode == ERR_BATTERY_LOW)
        {
            // Battery recovered or current power is USB, clear stale low-battery error
            errorActive = false;
            activeErrorCode = ERR_NONE;
            errorCritical = false;
            haltIMU = false;
        }
    }
}
// --- MAIN LOOP (CORE 1) ---
void loop()
{
    crsf->update();
}

// --- CRSF CALLBACK (Called from loop) ---
void onReceiveRcChannels(serialReceiverLayer::rcChannels_t *rcChannels)
{
    bool fs = rcChannels->failsafe;

    isFailsafeActive = fs;

    if (!fs)
    {
        int rawSteer = rcChannels->value[0];

        int baseSteer = map(rawSteer, 172, 1811, SERVO_ATTACH_MIN, SERVO_ATTACH_MAX);
        const int baseCenter = (SERVO_ATTACH_MIN + SERVO_ATTACH_MAX) / 2;
        mappedSteer = baseSteer + (SERVO_CENTER - baseCenter);
        mappedSteer = constrain(mappedSteer, SERVO_ATTACH_MIN, SERVO_ATTACH_MAX);
        //Serial.printf("raw Steer: %d Base Steer: %d | Mapped Steer: %d\n",rawSteer, baseSteer, mappedSteer);
        steering.writeMicroseconds(mappedSteer);

        currentThrottlePWM = rcChannels->value[2];
        Automatic = rcChannels->value[4] > 1000;
        launchControl = rcChannels->value[11] > 1000;
        //
        isLinkUp = true;
        button7 = rcChannels->value[7] > 1000;

        if (button7)
        {
            slavePower.disableMotor();
        }
        else
        {
            slavePower.enableMotor();
        }

        if (rcChannels->value[6] < 250)
        {
            button = 0;
        }
        else if (rcChannels->value[6] < 1000)
        {
            button = 250;
        }
        else
        {
            button = 750;
        }
        
        
        if (rcChannels->value[10] < 1000)
        {
            disableIMU  = true;
            haltIMU = false;

        }else{
            disableIMU = false;

        }
        static bool lcStagingReady = false;
        static bool lcLaunchPhase = false;
        static unsigned long lcLaunchTimer = 0;
        if (rcChannels->value[8] < 1000) {
            brakeActive = false;
            lcStagingReady = false;
            lcStagingActive = false;
            lcLaunchPhase = false;
            lcLaunchTimer = 0;
            servo_break.writeMicroseconds(BRAKE_SERVO_CENTER_US);
        } else if (!launchControl || Automatic) {
            brakeActive = true;
            lcStagingReady = false;
            lcStagingActive = false;
            lcLaunchPhase = false;
            lcLaunchTimer = 0;
            servo_break.writeMicroseconds(BRAKE_SERVO_PRESSED_US);
        } else if (!slavePower.isMotorEnabled() && gearSwitch == 1 && button == 0) {
            // LC staging: brake held, motor off, gear 1, button at minimum
            brakeActive = true;
            lcStagingReady = true;
            lcStagingActive = true;
            lcLaunchPhase = false;
            lcLaunchTimer = 0;
            servo_break.writeMicroseconds(BRAKE_SERVO_PRESSED_US);
        } else if (lcStagingReady) {
            // LC launch: motor enabled after staging — hold brake 1s then release
            if (!lcLaunchPhase) {
                lcLaunchPhase = true;
                lcLaunchTimer = millis();
            }
            lcStagingActive = false;
            brakeActive = false;
            if (millis() - lcLaunchTimer < LAUNCH_CONTROL_BRAKE_HOLD_MS) {
                servo_break.writeMicroseconds(BRAKE_SERVO_PRESSED_US);
            } else {
                servo_break.writeMicroseconds(BRAKE_SERVO_CENTER_US);
            }
        } else {
            // motor was already on when brake was pressed — normal brake
            brakeActive = true;
            lcStagingActive = false;
            lcLaunchPhase = false;
            lcLaunchTimer = 0;
            servo_break.writeMicroseconds(BRAKE_SERVO_PRESSED_US);
        }
        
        
        if (rcChannels->value[5] < 250)
        {
            gearSwitch = 1;
        }
        else if (rcChannels->value[5] < 1200)
        {
            gearSwitch = 2;
        }
        else
        {
            gearSwitch = 3;
        }

        
        gearServoRaw = (int16_t)constrain(map(rcChannels->value[3], 172, 1811, 1200, 1800), 1200, 1800);
        
        AutomaticSpeed = map(rcChannels->value[9], 191, 1811, AUTOMATIC_MIN_SPEED, AUTOMATIC_MAX_SPEED);

        if (!disableIMU)
        {
            read_and_display_imu();
        }
    }
    else
    {
        isLinkUp = false;
    }
}
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

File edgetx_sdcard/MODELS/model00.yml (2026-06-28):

semver: 2.11.4
header: 
   name: "POCKET"
timers: 
   0:
      start: 0
      swtch: "NONE"
      value: 4185
      mode: OFF
      countdownBeep: 0
      minuteBeep: 0
      persistent: 0
      countdownStart: 0
      showElapsed: 0
      extraHaptic: 0
      name: ""
telemetryProtocol: 0
thrTrim: 0
noGlobalFunctions: 0
displayTrims: 0
ignoreSensorIds: 0
trimInc: 0
disableThrottleWarning: 0
displayChecklist: 0
extendedLimits: 1
extendedTrims: 0
throttleReversed: 0
enableCustomThrottleWarning: 0
disableTelemetryWarning: 0
showInstanceIds: 0
checklistInteractive: 0
customThrottleWarningPosition: 0
beepANACenter: 48
mixData: 
 -
   destCh: 0
   srcRaw: "I3"
   carryTrim: 0
   mixWarn: 0
   mltpx: ADD
   delayPrec: 0
   speedPrec: 0
   flightModes: 000000000
   weight: 100
   offset: 0
   swtch: "NONE"
   delayUp: 0
   delayDown: 0
   speedUp: 0
   speedDown: 0
   name: ""
 -
   destCh: 1
   srcRaw: "I1"
   carryTrim: 0
   mixWarn: 0
   mltpx: ADD
   delayPrec: 0
   speedPrec: 0
   flightModes: 000000000
   weight: 100
   offset: 0
   swtch: "NONE"
   delayUp: 0
   delayDown: 0
   speedUp: 0
   speedDown: 0
   name: ""
 -
   destCh: 2
   srcRaw: "I2"
   carryTrim: 0
   mixWarn: 0
   mltpx: ADD
   delayPrec: 0
   speedPrec: 0
   flightModes: 000000000
   weight: 100
   offset: 0
   swtch: "NONE"
   delayUp: 0
   delayDown: 0
   speedUp: 0
   speedDown: 0
   name: ""
 -
   destCh: 3
   srcRaw: "I0"
   carryTrim: 0
   mixWarn: 0
   mltpx: ADD
   delayPrec: 0
   speedPrec: 0
   flightModes: 000000000
   weight: 100
   offset: 0
   swtch: "NONE"
   delayUp: 0
   delayDown: 0
   speedUp: 0
   speedDown: 0
   name: ""
 -
   destCh: 4
   srcRaw: "SA"
   carryTrim: 0
   mixWarn: 0
   mltpx: ADD
   delayPrec: 0
   speedPrec: 0
   flightModes: 000000000
   weight: 100
   offset: 0
   swtch: "NONE"
   delayUp: 0
   delayDown: 0
   speedUp: 0
   speedDown: 0
   name: ""
 -
   destCh: 5
   srcRaw: "SB"
   carryTrim: 0
   mixWarn: 0
   mltpx: ADD
   delayPrec: 0
   speedPrec: 0
   flightModes: 000000000
   weight: 100
   offset: 0
   swtch: "NONE"
   delayUp: 0
   delayDown: 0
   speedUp: 0
   speedDown: 0
   name: ""
 -
   destCh: 6
   srcRaw: "SC"
   carryTrim: 0
   mixWarn: 0
   mltpx: ADD
   delayPrec: 0
   speedPrec: 0
   flightModes: 000000000
   weight: 100
   offset: 0
   swtch: "NONE"
   delayUp: 0
   delayDown: 0
   speedUp: 0
   speedDown: 0
   name: ""
 -
   destCh: 7
   srcRaw: "SD"
   carryTrim: 0
   mixWarn: 0
   mltpx: ADD
   delayPrec: 0
   speedPrec: 0
   flightModes: 000000000
   weight: 100
   offset: 0
   swtch: "NONE"
   delayUp: 0
   delayDown: 0
   speedUp: 0
   speedDown: 0
   name: ""
 -
   destCh: 8
   srcRaw: "SE"
   carryTrim: 0
   mixWarn: 0
   mltpx: ADD
   delayPrec: 0
   speedPrec: 0
   flightModes: 000000000
   weight: 100
   offset: 0
   swtch: "NONE"
   delayUp: 0
   delayDown: 0
   speedUp: 0
   speedDown: 0
   name: ""
 -
   destCh: 9
   srcRaw: "P1"
   carryTrim: 0
   mixWarn: 0
   mltpx: ADD
   delayPrec: 0
   speedPrec: 0
   flightModes: 000000000
   weight: 100
   offset: 0
   swtch: "NONE"
   delayUp: 0
   delayDown: 0
   speedUp: 0
   speedDown: 0
   name: ""
 -
   destCh: 10
   srcRaw: "MAX"
   carryTrim: 0
   mixWarn: 0
   mltpx: ADD
   delayPrec: 0
   speedPrec: 0
   flightModes: 000000000
   weight: 100
   offset: 0
   swtch: "L4"
   delayUp: 0
   delayDown: 0
   speedUp: 0
   speedDown: 0
   name: "f bba"
 -
   destCh: 11
   srcRaw: "MAX"
   carryTrim: 0
   mixWarn: 0
   mltpx: ADD
   delayPrec: 0
   speedPrec: 0
   flightModes: 000000000
   weight: 100
   offset: 0
   swtch: "L11"
   delayUp: 0
   delayDown: 0
   speedUp: 0
   speedDown: 0
   name: "dcbba"
limitData: 
   0:
      min: 0
      max: 0
      ppmCenter: 0
      offset: 0
      symetrical: 0
      revert: 0
      curve: 32
      name: ""
   1:
      min: 0
      max: 0
      ppmCenter: 0
      offset: 0
      symetrical: 0
      revert: 0
      curve: 32
      name: ""
   3:
      min: 0
      max: 0
      ppmCenter: 0
      offset: 0
      symetrical: 0
      revert: 0
      curve: 32
      name: ""
expoData: 
 -
   mode: 3
   scale: 0
   trimSource: 0
   srcRaw: "Rud"
   weight: 100
   offset: 0
   swtch: "NONE"
   curve: 
      type: 1
      value: 0
   chn: 0
   flightModes: 000000000
   name: ""
 -
   mode: 3
   scale: 0
   trimSource: 0
   srcRaw: "Ele"
   weight: 100
   offset: 0
   swtch: "NONE"
   curve: 
      type: 1
      value: 0
   chn: 1
   flightModes: 000000000
   name: ""
 -
   mode: 3
   scale: 0
   trimSource: 0
   srcRaw: "Thr"
   weight: 100
   offset: 0
   swtch: "NONE"
   curve: 
      type: 1
      value: 0
   chn: 2
   flightModes: 000000000
   name: ""
 -
   mode: 3
   scale: 0
   trimSource: 0
   srcRaw: "Ail"
   weight: 100
   offset: 0
   swtch: "NONE"
   curve: 
      type: 1
      value: 0
   chn: 3
   flightModes: 000000000
   name: ""
curves: 
   0:
      type: 0
      smooth: 1
      points: 0
      name: " bb"
   31:
      type: 1
      smooth: 0
      points: -1
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

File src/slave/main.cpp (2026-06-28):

#include <Arduino.h>
#include <ESP32Servo.h>
#include <Adafruit_NeoPixel.h>
#include <Wire.h>
#include <AS5600.h>
#include "shared/SharedData.h"
#include "pins.h"
#include "config.h"

Servo airServo;
Adafruit_NeoPixel StatusLed(NEOPIXEL_COUNT, STATUS_LED, NEO_GRB + NEO_KHZ800);
AS5600 as5600;

// --- SHARED DATA (Thread Safe) ---
volatile ControlPacket currentData;
volatile bool isConnectionActive = false;
SemaphoreHandle_t dataMutex;

// --- PROTOTYPES ---
void TaskComms(void *pvParameters);
void setFailsafe();
void updateServo(int targetGear, bool motorEnabled, bool isMoving, bool pistonMoving);

unsigned long lastSwitchTime = 0;
bool ledBlinkOn = false;
unsigned long lastBlinkTime = 0;
bool directionForward = true;
int delayMin = 0;

uint16_t prev_angle = 0;
unsigned long prev_time = 0;
float angular_speed = 0.0; // degrees per second

bool automaticPrev = false;
bool manualMotorPrev = false;
float automaticTargetSpeed = 0.0;
int servoPosition = SERVO_NEUTRAL_US;
long currentDelayTarget = DELAY_MAX_MS;
int currentGear = 2;
int lastServoGear = -1;
unsigned long gearShiftTimer = 0;
bool gearUpCondition = false;
bool gearDownCondition = false;
unsigned long lastStatusLogTime = 0;

void setup_NeoPixel()
{
    pinMode(STATUS_LED_PWR, OUTPUT);
    digitalWrite(STATUS_LED_PWR, HIGH);
    StatusLed.begin();
    StatusLed.clear();
    StatusLed.setBrightness(LED_BRIGHTNESS);
    StatusLed.fill(StatusLed.Color(255, 100, 0));
    StatusLed.show();
}

void setup()
{
    setup_NeoPixel();
    Serial.begin(921600);

    Wire.begin(SDA_PIN, SCL_PIN);
    as5600.begin();

    Serial1.begin(921600, SERIAL_8N1, UART_RX, UART_TX);

    pinMode(VALVE_A, OUTPUT);
    pinMode(VALVE_B, OUTPUT);
    digitalWrite(VALVE_A, LOW);
    digitalWrite(VALVE_B, LOW);
    pinMode(HALL_START, INPUT);
    pinMode(HALL_END, INPUT);
    delay(1000);

    ESP32PWM::allocateTimer(0);
    airServo.setPeriodHertz(333);
    airServo.attach(SERVO_REG, 500, 2500);
    airServo.write(servoPosition);

    dataMutex = xSemaphoreCreateMutex();

    xTaskCreatePinnedToCore(
        TaskComms,
        "Comms",
        4096,
        NULL,
        1,
        NULL,
        0);

    Serial.println("SLAVE ESP32-S3 Ready");
}

void loop()
{
    ControlPacket localData = {};
    bool connectionOK = false;

    if (xSemaphoreTake(dataMutex, (TickType_t)5) == pdTRUE)
    {
        memcpy(&localData, (const void *)&currentData, sizeof(ControlPacket));
        connectionOK = isConnectionActive;
        xSemaphoreGive(dataMutex);
    }

    // Read AS5600 raw angle and compute angular speed.
    uint16_t current_angle = as5600.rawAngle();
    unsigned long current_time = millis();
    if (prev_time != 0)
    {
        unsigned long delta_t = current_time - prev_time;
        if (delta_t > 0)
        {
            int16_t delta_angle = current_angle - prev_angle;
            if (delta_angle > 2048)
                delta_angle -= 4096;
            else if (delta_angle < -2048)
                delta_angle += 4096;
            angular_speed = (delta_angle * 360.0f / 4096.0f) / (delta_t / 1000.0f);
        }
    }
    prev_angle = current_angle;
    prev_time = current_time;
    bool isMoving = abs(angular_speed) > MOVING_SPEED_THRESHOLD;

    uint8_t targetR = 0;
    uint8_t targetG = 0;
    uint8_t targetB = 0;
    bool pistonMoving = false;
    bool motorActive = false;
    int targetGear = localData.Gear;

    if (connectionOK)
    {
        if (!localData.elrsActive)
        {
            setFailsafe();
            unsigned long now = millis();
            if (now - lastBlinkTime >= BLINK_INTERVAL_MS)
            {
                ledBlinkOn = !ledBlinkOn;
                lastBlinkTime = now;
            }
            if (ledBlinkOn)
            {
                targetR = 0;
                targetG = 255;
                targetB = 255;
            }
        }
        else if (localData.haltIMU)
        {
            setFailsafe();
            targetR = 0;
            targetG = 0;
            targetB = 255;
        }
        else if (localData.brake && !localData.launchControl)
        {
            setFailsafe();
            targetR = 255;
            targetG = 255;
            targetB = 0;
        }
        else
        {
            targetR = localData.motorEnable ? 0 : 255;
            targetG = localData.motorEnable ? 255 : 80;
            targetB = 0;

            if (localData.Automatic)
            {
                delayMin = localData.button;
                if (!automaticPrev)
                {
                    automaticPrev = true;
                    automaticTargetSpeed = (localData.AutomaticSpeed > 0) ? localData.AutomaticSpeed : AUTO_DEFAULT_SPEED;
                    currentDelayTarget = delayMin;
                    currentGear = 1;
                }
                else if (localData.AutomaticSpeed > 0 && localData.AutomaticSpeed != automaticTargetSpeed)
                {
                    automaticTargetSpeed = localData.AutomaticSpeed;
                }

                int speedTolerance = constrain(map(localData.throttle, 190, 1800, 1, 500), 20, 500);
                float targetLow = automaticTargetSpeed - speedTolerance;
                int maxAdjustment = AUTO_MAX_ADJUSTMENT;

                if (angular_speed > automaticTargetSpeed)
                {
                    int adjustment = constrain((int)((angular_speed - automaticTargetSpeed) * AUTO_KP), 1, maxAdjustment);
                    currentDelayTarget += adjustment;
                }
                else if (angular_speed < targetLow)
                {
                    int adjustment = constrain((int)((targetLow - angular_speed) * AUTO_KP), 1, maxAdjustment);
                    currentDelayTarget -= adjustment;
                }
                else
                {
                    currentDelayTarget += 1;
                }
                currentDelayTarget = constrain(currentDelayTarget, delayMin, DELAY_MAX_MS);
                motorActive = true;
                targetGear = currentGear;

                float gearUpThresh = min(automaticTargetSpeed * GEAR_UP_RATIO, GEAR_UP_SPEED);
                if (angular_speed >= gearUpThresh && currentGear == 1)
                {
                    if (!gearUpCondition)
                    {
                        gearUpCondition = true;
                        gearShiftTimer = millis();
                    }
                    else if (millis() - gearShiftTimer > GEAR_SHIFT_DELAY_MS)
                    {
                        currentGear = 3;
                        gearUpCondition = false;
                    }
                }
                else
                {
                    gearUpCondition = false;
                }
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

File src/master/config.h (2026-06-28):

#ifndef MASTER_CONFIG_H
#define MASTER_CONFIG_H

// ============================================================
//  MASTER CONFIG — all tunable values in one place
// ============================================================

// --- BATTERY ---
#define BATTERY_VOLTAGE_MIN             9.0f    // minimum cell voltage for 3S (V)
#define BATTERY_VOLTAGE_MAX             12.6f   // full charge for 3S (V)
#define BATTERY_VOLTAGE_CRITICAL        9.6f    // trigger low-battery error below this (V) — must be > MIN
#define BATTERY_DISCONNECTED_THRESHOLD  1.0f    // below this = battery unplugged (V)
#define BATTERY_DROP_THRESHOLD          2.0f    // rapid drop that indicates disconnection (V)
#define BATTERY_LOW_CONFIRM_COUNT       5       // consecutive low readings before error fires
#define BATTERY_LOW_IGNORE_MS           5000    // ignore low-battery for this long after rapid drop
#define BATTERY_READ_INTERVAL_MS        100     // ADC sampling interval in check_battery()
#define BATTERY_CHECK_TASK_INTERVAL_MS  500     // how often TaskSlaveComms calls check_battery()

// --- ADC ---
#define ADC_REF_VOLTAGE                 3.3f    // ESP32 ADC reference voltage
#define ADC_RESOLUTION                  4095    // 12-bit ADC range
#define IMON_CONVERSION_FACTOR          0.62f   // current sense: 10µA/A × 62kΩ
#define VBAT_DIVIDER_RATIO              6.60f   // resistor divider ratio on VBAT_REF pin

// --- STEERING SERVO ---
#define SERVO_ATTACH_MIN                600     // min PWM (µs)
#define SERVO_ATTACH_MAX                2400    // max PWM (µs)
#define SERVO_CENTER                    1400    // center position (µs)

// --- BRAKE SERVO ---
#define BRAKE_SERVO_CENTER_US           1500    // brake released (µs)
#define BRAKE_SERVO_PRESSED_US          700    // brake fully engaged (µs)

// --- LAUNCH CONTROL ---
#define LAUNCH_CONTROL_BRAKE_HOLD_MS    1000    // hold brake after motor enable before auto-release (ms)

// --- TILT DETECTION ---
#define TILT_WARNING_THRESHOLD          30.0f   // warning tilt angle (degrees)
#define TILT_CRITICAL_THRESHOLD         45.0f   // critical tilt angle (degrees)
#define TILT_ALERT_COOLDOWN_MS          1000    // min time between tilt alerts (ms)

// --- BRAKE LIGHTS ---
#define BRAKE_LIGHT_START               17      // first LED of the brake light group (same as KR_GROUP_START)

// --- KNIGHT RIDER BOOT / FAILSAFE ANIMATION ---
#define KR_GROUP_START                  17      // first physical LED of the grouped block
#define KR_VIRT_COUNT                   (KR_GROUP_START + 1)  // total virtual positions
#define KR_TAIL                         5       // number of fading tail LEDs
#define KR_STEP_MS                      45      // time per animation step (ms)
#define BOOT_ANIM_DURATION_MS           2000    // how long the boot animation plays (ms)

// --- LED EFFECT TIMING ---
#define ERROR_BLINK_INTERVAL_MS         500     // error state LED blink period (ms)
#define AUTO_PULSE_INTERVAL_MS          1000    // automatic mode pulse period (ms)
#define AUTO_PULSE_DURATION_MS          100     // automatic mode pulse on-time (ms)
#define BLUE_PULSE_INTERVAL_MS          1000    // IMU-active pulse period (ms)
#define BLUE_PULSE_DURATION_MS          100     // IMU-active pulse on-time (ms)
#define STROBE_PERIOD_MS                2000    // airplane strobe cycle period (ms)

// --- BEEPER ---
#define HALT_BEEP_FREQUENCY             1500    // IMU halt beep tone (Hz)
#define HALT_BEEP_DURATION_MS           150     // beep on-time (ms)
#define HALT_BEEP_INTERVAL_MS           1000    // time between beeps (ms)

// --- TASK TIMING ---
#define SLAVE_COMMS_LOOP_MS             20      // TaskSlaveComms loop period (~50 Hz)


#define AUTOMATIC_MAX_SPEED             6000
#define AUTOMATIC_MIN_SPEED             1000
#define LAUNCH_CONTROL                  true

#endif // MASTER_CONFIG_H

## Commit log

2026-01-26 Add initial project structure with configuration files, source code, and documentation
    - Created .gitignore to exclude build artifacts and IDE settings
    - Added README files for project directories explaining their purpose
    - Introduced PlatformIO configuration in platformio.ini for master and slave environments
    - Implemented main functionality in master and slave source files
    - Defined pin mappings in pins.h for both master and slave
    - Included shared data structure for communication between master and slave
    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
2026-01-31 Update desktop.ini files to reflect new Google Drive File Stream version and modify pin definitions in pins.h
2026-03-22 Add core functionality for master and slave communication
    - Implemented error handling with error codes in errors.h
    - Defined function prototypes in functions.h for buzzer, IMU calibration, and gear control
    - Created globals.cpp and globals.h for shared variables and objects
    - Developed main.cpp to handle setup, loop, and communication with slave
    - Added pin definitions in pins.h for master and slave
    - Implemented setup functions in setups.cpp for various components including buzzer, CRSF, servos, and IMU
    - Created tilt detection logic in tilt_detection.cpp and tilt_detection.h
    - Established shared data structure in SharedData.h for communication packets
    - Added desktop.ini files for directo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
    [ELRS.h, class.h, errors.h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]
2026-04-09 Fix: resolve merge conflicts in main.cpp and pins.h
    [main.cpp, pins.h]
2026-04-13 Fix: resolve merge conflicts in loop() and setFailsafe() functions
    [main.cpp]
2026-04-13 Fix: update failsafe logic and improve LED status handling in loop()
    [main.cpp]
2026-04-21 Refactor and enhance functionality in master and slave modules
    - Updated comments and variable names for clarity and consistency across the codebase.
    - Added a new function `requestBeepPattern` in `main.cpp` to manage beep requests with priority handling.
    - Implemented a `check_battery` function to monitor battery status and handle transitions between battery and USB power.
    - Enhanced the NeoPixel setup in `setups.cpp` to include a test pattern for better visibility.
    - Improved tilt detection logic in `tilt_detection.cpp` with clearer comments and structure.
    - Introduced automatic gear shifting logic in the slave module based on angular speed.
    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
2026-04-24 Refactor pin assignments and improve servo control logic
    - Updated pin assignments in pins.h for SERVO_BRAKE and SERVO_STEER.
    - Enhanced setup_ServoPWM function to include brake servo initialization and error handling.
    - Modified setup_NeoPixel to adjust brightness and removed unnecessary test pattern.
    - Added new brake field to ControlPacket in SharedData.h for improved control.
    - Refactored main loop in slave/main.cpp to handle brake logic and servo gear control more effectively.
    - Introduced config.h files for both master and slave to centralize tunable parameters.
    - Added constants for battery management, servo settings, and automatic mode parameters.
    [config.h, globals.cpp, main.cpp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]
2026-05-04 Remove redundant servo control logic in loop() function
2026-06-01 Adjust automatic speed mapping and enhance gear shifting logic
2026-06-01 Fix typos, improve code readability, and optimize gear shifting logic
    [main.cpp]
2026-06-28 Final Fix
    [bom.xlsx, pick-and-place.xlsx, schema.dxf]
